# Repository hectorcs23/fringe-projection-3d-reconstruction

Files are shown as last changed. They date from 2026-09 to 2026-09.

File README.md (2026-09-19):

# 3D Reconstruction by Fringe Projection & Phase Shifting

Structured-light 3D scanner built from a consumer camera and a mini projector. Sinusoidal fringe patterns are projected onto an object, the phase of the deformed fringes is recovered with a **4-step phase-shifting** algorithm, unwrapped with **multi-frequency temporal unwrapping**, converted to height by **triangulation**, and exported as a **3D-printable STL**.

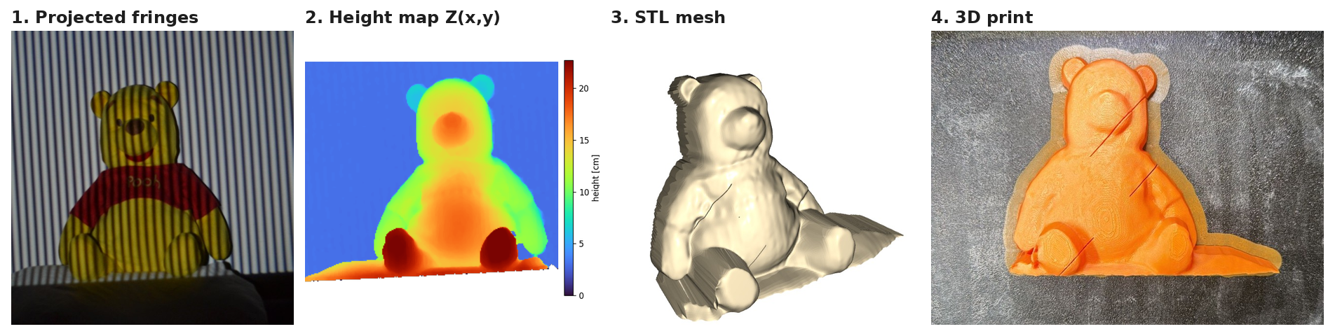
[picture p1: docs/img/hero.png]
Pipeline: fringes → height map → STL → 3D print


> Optics course project (ITESM Monterrey, 2026) — Hector Enrique Campbell Salas & José Feliciano Gutiérrez Rubio.
> Full report (Spanish): [`docs/Reporte_Final_fringe_projection_ES.pdf`](docs/Reporte_Final_fringe_projection_ES.pdf)

## Results at a glance

| Metric | Value |
|---|---|
| Valid pixels after modulation mask | **69.2 %** |
| Fringe frequencies (measured by FFT) | 2, 4, 18, 70 fringes across the field |
| Reconstructed object height | ~13 cm |
| Height error vs. 11 tape-measured landmarks | **RMSE 1.75 cm**, MAE 1.39 cm |
| Leave-one-out RMSE (honest out-of-sample) | 2.09 cm |
| Mono- vs multi-frequency difference (validation sphere) | up to ~0.4 rad (~7 mm) at the center |

The largest errors sit exactly where the physics predicts them: red regions (shirt) absorb the projected light and kill fringe modulation, and the steep sides of the object sit in projector shadows.

## How it works

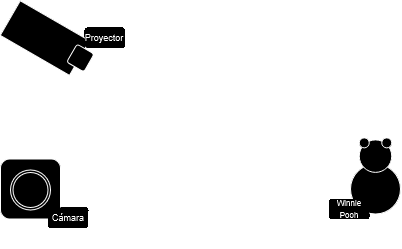
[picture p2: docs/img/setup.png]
Setup


Camera (Canon M50 Mark II) and projector sit side by side, **L = 1450 mm** from a white reference board, with a baseline **d**. For each frequency, four patterns shifted by 0, π/2, π, 3π/2 are captured on the reference board and on the object.

1. **N-step phase shifting.** Each capture follows $I_k = A + B\cos(\varphi + \delta_k)$ with $\delta_k = 2\pi k/N$, so

```math
\varphi = \mathrm{atan2}\left(-\sum_k I_k \sin\delta_k,\ \sum_k I_k \cos\delta_k\right), \qquad B = \frac{2}{N}\sqrt{C^2 + S^2}
```

2. **Modulation mask.** Keep pixels with $B > \alpha \max B$ (drops shadows, saturation, dark/red regions).
3. **Object − reference** wrapped phase difference at each frequency.
4. **Multi-frequency temporal unwrapping.** The low frequency (no 2π jumps) sets the fringe order of the next one:

```math
k_m = \mathrm{round}\left[\frac{\frac{N_m}{N_{m-1}}\Phi_{m-1} - \varphi_m}{2\pi}\right], \qquad \Phi_m = \varphi_m + 2\pi k_m
```

5. **Phase → height.** Linear triangulation with $K = Lp/(2\pi d) \approx 17.9$ mm/rad for the 70-fringe pattern:

```math
h(x,y) = K \, \Delta\varphi(x,y)
```

6. **Meshing.** Each 2×2 block of valid pixels becomes two triangles → STL (Open3D), smoothed and printed.

## Validation: sphere first

A polystyrene hemisphere was reconstructed with single-frequency spatial unwrapping and with multi-frequency temporal unwrapping. Multi-frequency recovered more detail at the center, so it was used for the complex object.

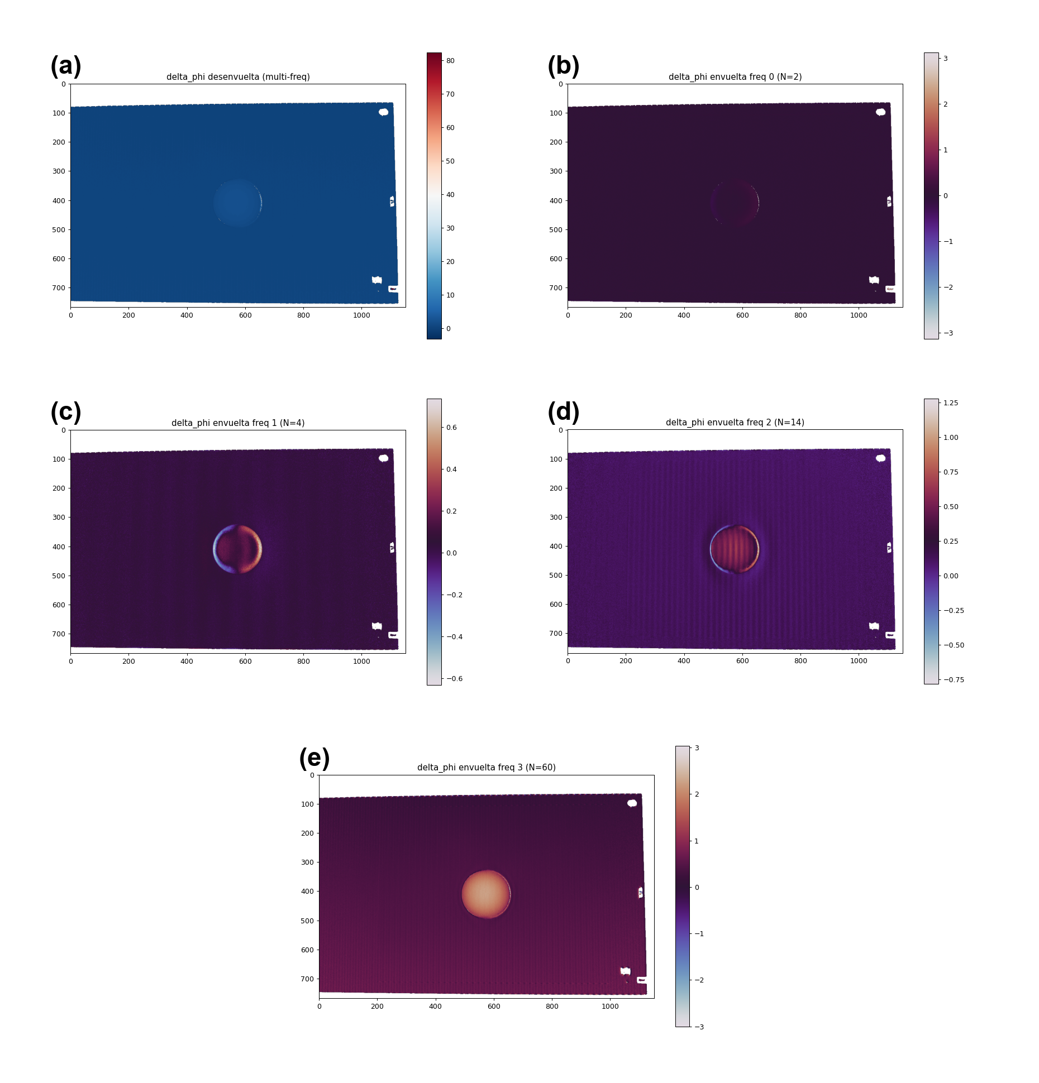
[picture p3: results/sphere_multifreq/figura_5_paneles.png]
Multi-frequency on the sphere


## Error analysis

11 landmarks (feet, hands, ears, eyes, nose, belly, shirt) were measured with a tape measure (±0.1 cm) and compared against the reconstruction (`src/error.py`), including leave-one-out validation of the phase→cm calibration.

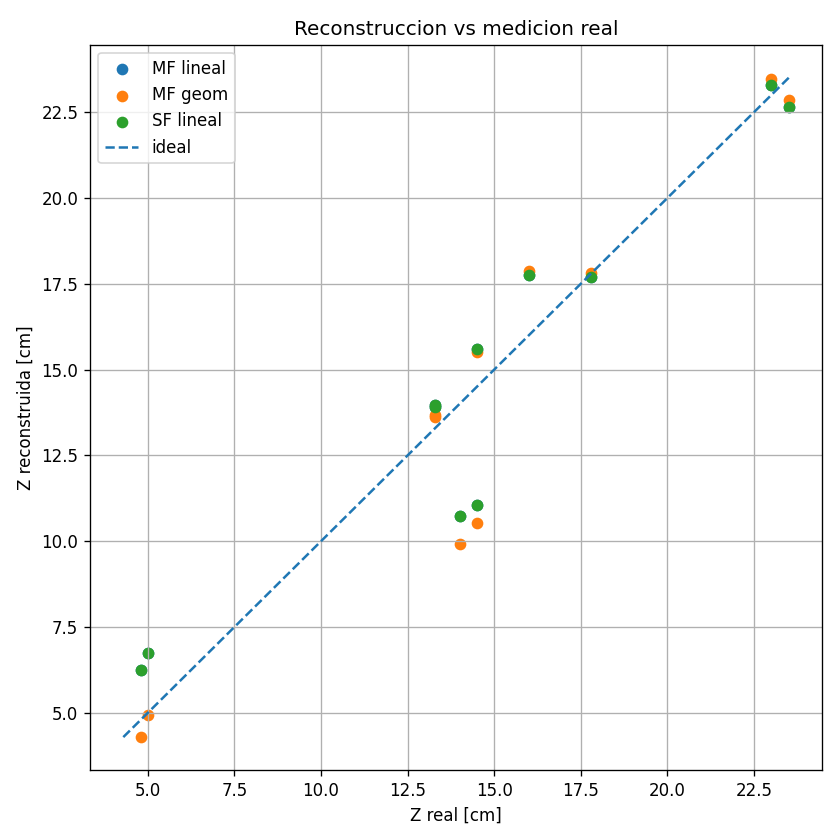
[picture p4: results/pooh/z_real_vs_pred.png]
Real vs reconstructed


## What didn't work (and what I'd do next)

I also captured the object from several angles (3 × 120° and 12 × 30°) and tried to fuse the views with ICP. Without a calibrated turntable the views don't share a known rotation axis, so the point clouds never registered cleanly, and the final model uses the frontal view only. Next steps:

- calibrated rotary stage or fiducial markers for multi-view registration,
- full triangulation equation instead of the linear approximation,
- camera/projector calibration (intrinsics + gamma) to reduce systematic phase error.

## Repository layout

```
src/
  phase_shifting.py      core library: N-step phase, mask, multi-freq unwrap, phase→height
  SuperficieSTL.py       heightmap → triangle mesh → STL (Open3D)
  process_pooh.py        main pipeline on the plush toy (front view)
  generate_pooh_stl.py   calibrated height map → printable STL
  error.py               landmark-based error analysis (MAE/RMSE, LOO, Monte Carlo)
  sphere_multifreq.py    validation: multi-frequency on the hemisphere
  sphere_singlefreq.py   validation: single-frequency on the hemisphere
  compare_methods.py     mono- vs multi-frequency comparison
  measure_freqs.py       measures real fringe counts via FFT
  demo_synthetic.py      self-contained synthetic demo (no photos needed)
data/
  pooh_front/            32 photos: 4 freq × 4 shifts, object + reference (downscaled)
  sphere/                32 photos: same protocol on the hemisphere (downscaled)
results/                 figures, STL, error tables
docs/                    report (Spanish) and README images
```

## Run it

```bash
pip install -r requirements.txt
python src/process_pooh.py        # phase maps, mask, unwrapped phase -> results/pooh/
python src/generate_pooh_stl.py   # -> results/pooh/pooh.stl
python src/error.py               # error analysis (reuses saved landmark picks)
python src/sphere_multifreq.py    # validation on the hemisphere
```

Run from the repository root. Photos in `data/` are downscaled copies of the originals (Canon M50, 4608×3072); the full-resolution captures are available on request.

## Stack

Python · NumPy · SciPy · scikit-image · Pillow · Matplotlib · Open3D · SolidWorks (mesh cleanup) · FDM 3D printing

## References

1. R. Juarez-Salazar, S. Esquivel-Hernandez, V. H. Diaz-Ramirez, "Optical Fringe Projection: A Straightforward Approach to 3D Metrology," *Metrology* 5, 47 (2025).
2. K. J. Gåsvik, *Optical Metrology*, 3rd ed., Wiley (2002).
3. E. Hecht, *Optics*, 5th ed., Pearson (2017).

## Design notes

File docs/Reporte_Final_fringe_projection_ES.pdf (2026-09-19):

Reconstrucción 3D mediante proyección de franjas y desplazamiento de fase

Hector Enrique Campbell Salas and José Feliciano Gutiérrez Rubio Instituto Tecnológico de Estudios Superiores de Monterrey (Dated: 3 de mayo de 2026)

I. OBJETIVO

Implementar un sistema de reconstrucción tridimensional basado en proyección de franjas, con el propósito de comprender cada etapa de la técnica: desde la proyección de patrones sinusoidales y la captura de imágenes, pasando por la recuperación de fase mediante desplazamiento de fase y desenvolvimiento multifrecuencia, hasta la conversión geométrica a un mapa de altura y la generación de una malla STL. El sistema se valida primero con un objeto de geometría conocida (semiesfera) y posteriormente se aplica a un objeto de geometría compleja (peluche de "Winnie pooh") para evaluar el desempeño de la técnica en condiciones más robustas.

II. DESCRIPCIÓN

Se implementa un sistema de reconstrucción tridimensional basado en metrología óptica por proyección de franjas, con el propósito de registrar con una cámara la deformación aparente de dichas franjas sobre su superficie, el arreglo óptico se muestra en la figura 1.

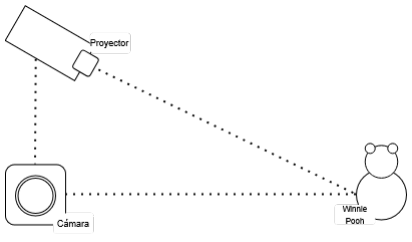
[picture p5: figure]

Figura 1. Arreglo experimental utilizado para la proyección de franjas, mostrando la posición relativa entre el proyector, la cámara y el objeto.

Se capturaron imágenes de referencia sobre una cartulina plana y posteriormente imágenes de un oso de peluche "Winnie Pooh". Se aplicó un algoritmo de desplazamiento de fase de cuatro pasos para recuperar la fase envuelta del patrón. Después, mediante un esquema multifrecuencia, se realizó el desenvolvimiento de fase para obtener una fase continua asociada al relieve de la superficie. Finalmente, la fase desenvuelta se convirtió en un mapa escalar de alturas. Con dicho mapa se generó una malla tipo STL, la cual puede utilizarse para visualización o impresión 3D.

A. Materiales y equipo

Cámara digital Canon M50 Mark II.

Proyector digital Bigview Mini Proyector HY300.

Cartulina blanca de 50 × 65 cm como plano de referencia.

Semiesfera de poliestireno como objeto de geometría conocida.

Peluche “Winnie Pooh” como objeto de geometría compleja.

Computadora con Python 3.12 para el procesamiento de imágenes.

SolidWorks y Open3D para visualización, edición y exportación del modelo 3D.

III. MARCO TEÓRICO

A. Metrología óptica

La metrología óptica es una rama de la óptica que mide propiedades físicas un objeto, tales como su forma, distancia, altura y superficie.
En dicha área, conocer la fase es importante pues está directamente relacionada con el camino óptico que recorre la luz al incidirla sobre cualquier objeto. Además esta relación permite entender por qué pequeños cambios geométricos en una superficie pueden producir cambios medibles en la fase de la luz.
Sin embargo, las cámaras registran intensidades y no la fase, por ello son necesarios crear métodos experimentales y computacionales que permitan recuperar la información física del objeto a estudiar a partir de imágenes de intensidad.
B. Proyección de Franjas

La proyección de franjas es una técnica de metrología óptica en la que se ilumina un objeto con un patrón pe-

2

riódico de franjas claras y oscuras. Al proyectarse sobre una superficie plana, el patrón observado se mantiene regular; sin embargo, cuando incide sobre una superficie con relieve, la forma del objeto modifica la rectitud y posición aparente de las franjas [1]. Esta deformación corresponde a una alteración de fase, por lo que la información geométrica de la superficie puede recuperarse mediante el análisis del patrón capturado por la cámara [1, 2].

C. Recuperación de Fase Mediante Desplazamiento de Fase

La intensidad registrada para el k-ésimo patrón está dada por:

Ik(x, y) = A(x, y) + B(x, y) cos[φ(x, y) + δk] (1)

donde A(x, y) representa la componente promedio de iluminación, B(x, y) la modulación o contraste local de las franjas, φ(x, y) la fase que se desea recuperar y δk el desfase conocido aplicado al k-ésimo patrón [2].
La ecuación (1) contiene tres incógnitas por píxel: A, B y ϕ. Por ello, una sola imagen no es suficiente para determinar la fase. Es así que se realiza un desarrollo matemático descrito en el Apéndice A y se obtienen las siguientes expresiones:
φ(x, y) = atan2(S, C), | (2)

B(x, y) = 2
N

p
C² + S², | (3)

A(x, y) = 1
N

N

X⁻¹

k=0

Ik(x, y), | (4)

donde (2) representa la fase recuperada, (3) la modulación píxel a píxel y (4) la componente de fondo.

D. Desplazamiento de Fase: Cuatro Pasos

En particular, para N = 4, los desfases aplicados al patrón proyectado son:

δk = 0,

π
2

, π,

3π
2
. | (5)

Este caso permite obtener dos componentes en cuadratura de la señal de franjas: una asociada a cos ϕ y otra asociada a sin ϕ. Sustituyendo estos desfases en el modelo de intensidad, se obtiene:

I0 = A + B cos ϕ, | (6)
I1 = A − B sin ϕ, | (7)
I2 = A − B cos ϕ, | (8)
I3 = A + B sin ϕ. | (9)

Al combinar imágenes separadas por un desfase de π, la componente promedio de iluminación se cancela, mientras que la parte modulada se conserva. A partir de estas dos componentes, la fase envuelta se obtiene mediante la ecuación (10)

ϕenv(x, y) = atan2 [I3 − I1, I0 − I2] . (10)

Este esquema es conveniente porque elimina la componente de fondo antes de calcular la fase y reduce la dependencia directa con la amplitud local de las franjas. No obstante, la fase obtenida mediante (10) permanece restringida al intervalo (−π, π], por lo que la fase obtenida corresponde a una fase envuelta.

E. Desenvolvimiento Mediante Monofrecuencia

El desenvolvimiento mediante monofrecuencia parte de una única fase envuelta φ

w(x, y) ∈ (−π, π] y busca recuperar una fase continua Φ(x, y) a partir de la comparación entre píxeles vecinos. La idea principal es que, si la superficie es continua y el ruido es bajo, la diferencia de fase entre puntos adyacentes debe ser pequeña. Cuando aparece un salto cercano a ±2π, este se interpreta como una discontinuidad artificial producida por la naturaleza periódica de la fase envuelta. En ese caso, el algoritmo corrige la fase sumando o restando múltiplos de 2π, con el fin de reconstruir una fase continua. De esta forma, el método convierte una fase limitada al intervalo (−π, π] en una fase continua que puede relacionarse con la geometría del objeto.
Sin embargo, este procedimiento depende de la continuidad espacial de la superficie. Si existen discontinuidades reales de altura, sombras, o regiones con baja modulación, el algoritmo puede confundir un salto físico con un salto artificial de fase. Por esta razón, el desenvolvimiento espacial monofrecuencia es adecuado para superficies suaves, pero puede ser insuficiente en objetos con geometría compleja donde se requiere un desenvolvimiento mediante multifrecuencia.
F. Desenvolvimiento Mediante Multifrecuencia

Para objetos con geometrías complejas se utiliza un algoritmo mediante multifrecuencia. El algoritmo consiste en la proyección de franjas a diferentes frecuencias, además el algoritmo es recursivo ya que comienza

3

desde frecuencias bajas hasta las frecuencias más altas. Las frecuencias bajas presentan menos saltos de fase, sin embargo, sirven como guía para determinar el orden correcto de franja. Por otro lado, las frecuencias altas proporcionan mayor sensibilidad a los cambios de altura y permiten recuperar más detalles de la superficie. Sea Φm(x, y) la fase desenvuelta a la frecuencia Nm. Para cada frecuencia Nm, se obtiene primero una fase envuelta φ

w
m(x, y). A partir de la fase desenvuelta de la frecuencia anterior, Φm−1(x, y), se estima la fase esperada en la nueva frecuencia. La estimación se expresa en la ecuación (11)

Φ

esp

m (x, y) = Nm

Nm−1

Φm−1(x, y). | (11)

Donde Nm−1 es la frecuencia anterior y Φm−1(x, y) es la fase anterior.
Posteriormente, se determina el orden de franja entero km que más cerca está de la fase esperada:
km(x, y) = round
Φ

esp
m (x, y) − ϕ

w
m(x, y)
2π
. (12)

Finalmente, se reconstruye la fase desenvuelta a la nueva frecuencia:

Φm(x, y) = ϕ

w
m(x, y) + 2πkm(x, y). | (13)
G. De fase a altura: Triangulación

La fase desenvuelta no representa directamente la altura del objeto, solo indica cómo se desplazó el patrón de franjas observado por la cámara respecto a una referencia plana. Para convertir esa diferencia de fase en una magnitud geométrica, es necesario utilizar la geometría del sistema cámara-proyector.
La diferencia de fase se relaciona con el desplazamiento lateral del patrón. Si p es es el periodo de las franjas sobre el plano de referencia, entonces el desplazamiento asociado a la diferencia de fase se expresa según la ecuación (14)

AB =

p ∆ϕ(x, y)
2π
. | (14)

Por triángulos semejantes, este desplazamiento se relaciona con la altura h(x, y) del objeto. Para el modelo geométrico utilizado, la altura puede expresarse según la ecuación (15).

h(x, y) = L ∆ϕ(x, y)
∆ϕ(x, y) −

2πd
p
, | (15)

donde L es la distancia del proyector al plano de referencia, d es la línea de base entre proyector y cámara, y p el periodo de franjas proyectadas sobre el plano de referencia.

IV. METODOLOGÍA

A. Arreglo experimental y selección de objetos

Se seleccionaron dos objetos para evaluar el método de reconstrucción. El primer objeto fue una media esfera de poliestireno, utilizada como prueba inicial debido a su geometría simple y superficie relativamente uniforme. El segundo objeto fue un oso de peluche “Winnie Pooh”, elegido por presentar una geometría más compleja, textura superficial y variaciones de color.
El arreglo experimental estuvo compuesto por un proyector, una cámara digital, una cartulina utilizada como plano de referencia y el objeto a reconstruir. El proyector y la cámara se colocaron aproximadamente en el mismo plano horizontal, separados por una línea de base d. La distancia entre el proyector y el plano de referencia fue L. Durante la captura se mantuvo fija la posición relativa entre cámara, proyector y plano de referencia, con el fin de evitar cambios artificiales en la fase medida.

Tabla I. Parámetros geométricos del arreglo experimental.

Parámetro | Símbolo | Valor
Distancia proyector–plano | L | 1450 mm
Línea de base proyector–cámara | d | 200 mm
Cartulina iluminada (ancho) | – | 650 mm
Cartulina iluminada (alto) | – | 500 mm
Resolución cámara (orig.) | – | 4608 × 3072
B. Proyección de franjas y captura de imágenes

Para la captura experimental se proyectaron patrones sinusoidales de franjas sobre una cartulina utilizada como plano de referencia y, posteriormente, sobre el objeto a reconstruir.
Debido a que la cámara y el proyector se encontraban separados horizontalmente, las franjas proyectadas fueron verticales. Esta orientación permite que los cambios de altura del objeto produzcan un desplazamiento aparente de las franjas en la dirección donde varía la fase.
Para cada frecuencia se proyectaron cuatro patrones con desplazamientos de fase de 0, π/2, π y 3π/2. Este procedimiento se realizó primero sobre el plano de referencia y después sobre el objeto seleccionado, manteniendo fija la posición relativa entre cámara, proyector y plano de referencia.

4

C. Procesamiento general

El procesamiento de las imágenes siguió el flujo mostrado en la Fig. 2. El algoritmo computacional recibe

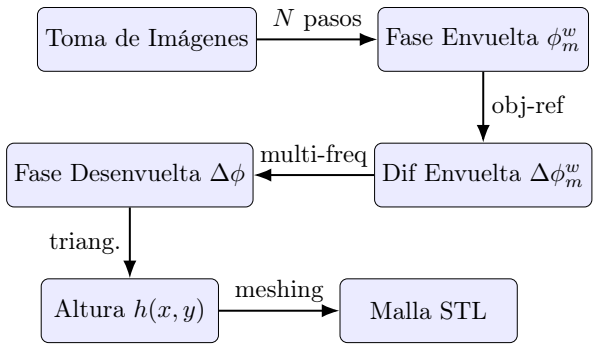
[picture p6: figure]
Toma de Imágenes; Fase Envuelta ϕ; Dif Envuelta ∆ϕ; w Fase Desenvuelta ∆ϕ; Altura h(x, y); Malla STL; N pasos; obj-ref; multi-freq; triang.; meshing

Figura 2. Procesamiento computacional implementado para la reconstrucción 3D de los objetos seleccionados.

como entrada las imágenes JPG correspondientes a cada frecuencia y desfase. Después, mediante el algoritmo de N pasos, se obtuvo la fase envuelta ϕ

w
m para cada
frecuencia m.
Posteriormente se calculó la diferencia de fase envuelta entre el objeto y la referencia, ∆ϕ

w
m. Esta resta permitió reducir la contribución del fondo y conservar principalmente la deformación del patrón producida por el relieve del objeto. Después se aplicó el desenvolvimiento multifrecuencia para obtener una fase continua ∆ϕ. Finalmente, esta fase se convirtió en un mapa de alturas h(x, y), a partir del cual se generó una malla STL.
D. Recuperación de fase por cuatro pasos

Una vez capturadas las imágenes, se aplicó el algoritmo de desplazamiento de fase de cuatro pasos para cada frecuencia proyectada. Este proceso se realizó por separado para las imágenes de referencia y para las imágenes del objeto.
A partir de estas capturas, el algoritmo permitió obtener tres mapas principales: la fase envuelta, la modulación de las franjas y la componente promedio de iluminación. La fase envuelta contiene la información asociada a la deformación del patrón; la modulación indica la calidad local de las franjas; y la componente promedio permite identificar regiones demasiado oscuras o saturadas.
Computacionalmente, esta etapa se implementó mediante una función que recibe una lista de imágenes desplazadas en fase y devuelve la fase envuelta, la modulación y la componente promedio. En el pipeline, esta etapa corresponde al paso de imágenes JPG a fase envuelta ϕ

w
m.
E. Desenvolvimiento multifrecuencia

Para resolver la ambigüedad de fase se utilizó un desenvolvimiento temporal multifrecuencia. Primero, para cada frecuencia proyectada, se obtuvo una fase envuelta tanto del plano de referencia como del objeto. Posteriormente, se calculó la diferencia envuelta objeto– referencia para cada frecuencia, de modo que la fase común del patrón proyectado se cancelara antes del desenvolvimiento.
Las diferencias de fase se ordenaron de menor a mayor frecuencia. La frecuencia más baja se utilizó como punto de partida debido a que contiene menos discontinuidades de 2π. Después, el algoritmo utilizó esta fase como guía para desenvolver progresivamente las fases de frecuencias mayores. Este proceso permitió combinar la estabilidad de las frecuencias bajas con la mayor sensibilidad de las frecuencias altas.
Una vez realizado lo anterior, se obtuvo una fase desenvuelta continua que fue utilizada como entrada para la conversión de fase a altura.
F. De fase desenvuelta a modelo 3D

Una vez obtenida la fase desenvuelta ∆φ(x, y) mediante el desenvolvimiento multifrecuencia, se convirtió la información de fase en un mapa de altura. Primero se aplicó una máscara basada en la modulación B(x, y), con el fin de conservar únicamente las zonas donde las franjas se distinguían con suficiente claridad. De esta manera se descartaron regiones con sombras, saturación, bajo contraste o absorción de luz por parte del objeto.
Posteriormente, sobre los píxeles válidos se aplicó la relación fase–altura descrita en la sección III.G. En la implementación final se utilizó una calibración lineal de la forma
h(x, y) = K∆φ(x, y), | (16)

donde K = 17,9 mm/rad corresponde a la constante utilizada para la frecuencia más alta. Con esta conversión se obtuvo un mapa de altura en milímetros para cada vista capturada.
Después, cada píxel válido del mapa de altura se interpretó como un punto tridimensional (X, Y, Z), donde X e Y representan la posición lateral en la imagen y Z = h(x, y) la altura reconstruida. De esta manera se generó una nube de puntos asociada a cada vista del objeto.
Para intentar reconstruir el objeto completo, se capturaron distintas vistas del peluche y se intentó alinearlas mediante ICP (Iterative Closest Point). Sin embargo, al no contar con una base rotatoria calibrada, las

5

vistas no compartieron un eje de rotación común. Esto produjo desplazamientos entre las nubes de puntos y evitó una alineación estable. Por esta razón, el modelo final se construyó únicamente a partir de la vista frontal.
Finalmente, la nube de puntos frontal se convirtió en una malla triangular conectando píxeles vecinos válidos. La malla resultante se exportó en formato STL, lo que permitió visualizarla en Open3D, editarla en Solid-Works e imprimirla en 3D. Los detalles computaciones se presentan en el Apéndice B.
V. RESULTADOS

Esta sección presenta los resultados obtenidos en dos etapas. Primero se utilizó una semiesfera como objeto de prueba para comparar el desenvolvimiento monofrecuencia y multifrecuencia, con el fin de seleccionar la metodología más adecuada para un objeto de mayor complejidad. Posteriormente se aplicó el algoritmo seleccionado a la reconstrucción de un peluche tipo ‘Winnie Pooh’.
Para el caso de la semiesfera, se realizaron tanto el desenvolvimiento por una frecuencia así como el multifrecuencia y se observaron los resultados con el fin de saber la metodología a seguir en un objeto más robusto. Se usaron las mismas foto y se muestra la diferencia entre los procesos de desenvolvimiento. Para el caso

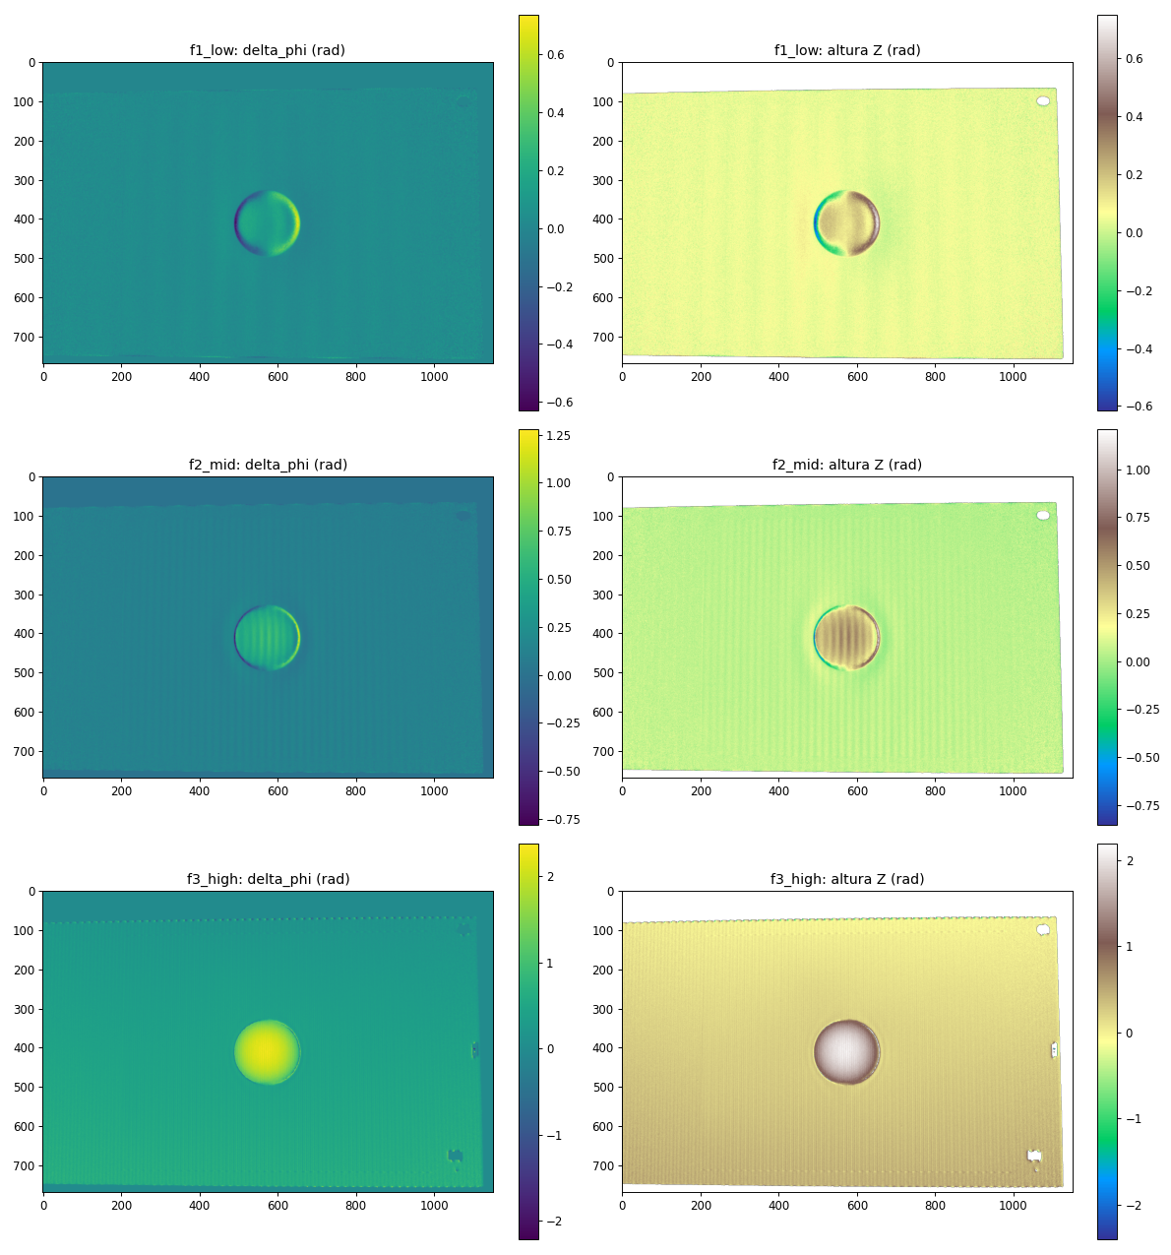
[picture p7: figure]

Figura 3. Fases recuperadas para la semiesfera utilizando cada una de las frecuencias proyectadas

Y después mediante el algoritmo de multifrecuencias:

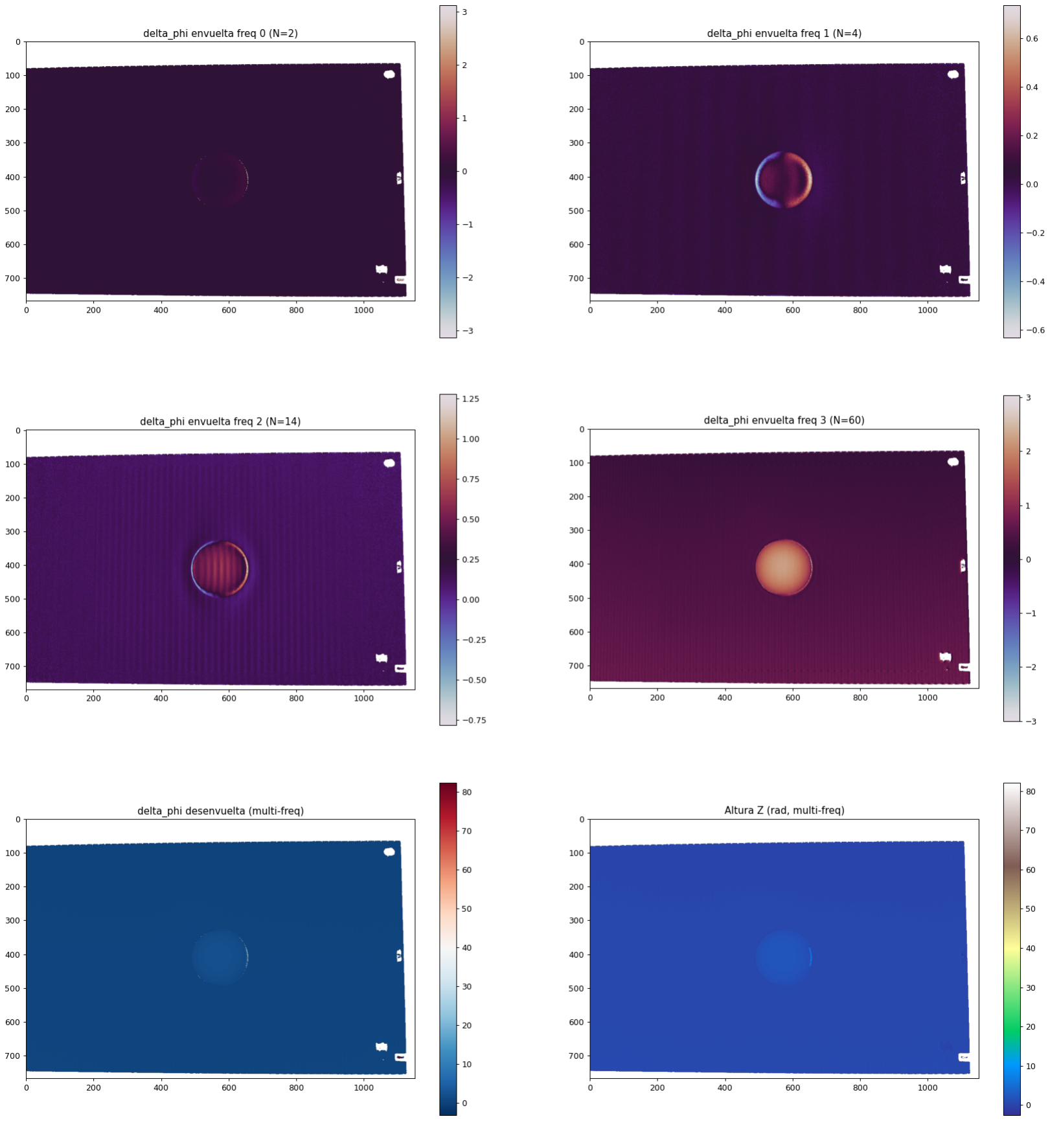
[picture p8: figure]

Figura 4. Resultado del desenvolvimiento multifrecuencia aplicado a la semiesfera.

La diferencia entre el desenvolvimiento de la frecuencia más alta y el desenvolvimiento de multifrecuencia llegó a un máximo de 0.4 rad, alrededor de 7 milimetros en el centro. Se observa que el resultado obtenido por multifrecuencia (Fig. 4) presenta mayor nivel de detalle en el centro de la esfera en comparación con el desenvolvimiento monofrecuencia (Fig. 3).

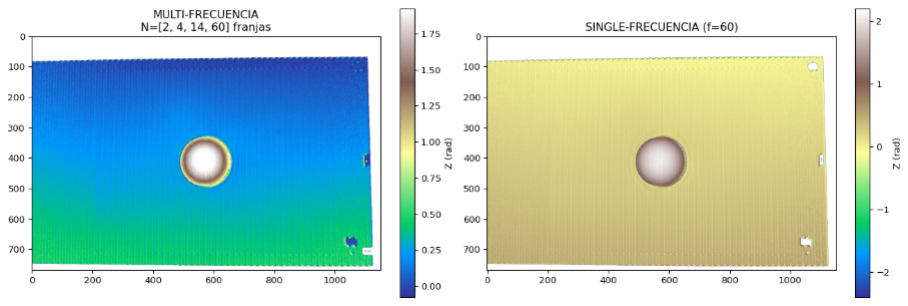
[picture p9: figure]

Figura 5. Comparación entre la fase obtenida mediante desenvolvimiento monofrecuencia y multifrecuencia.

6

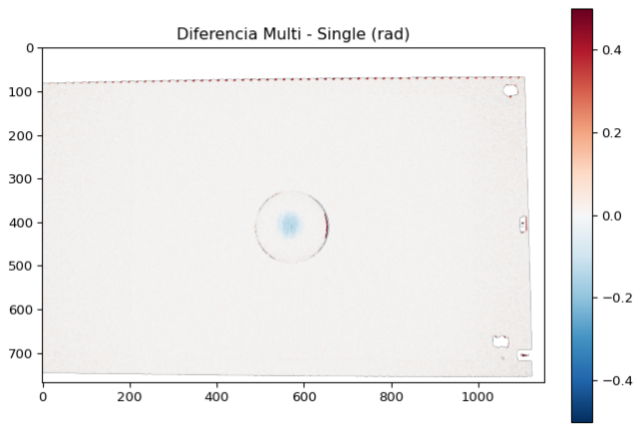
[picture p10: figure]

Figura 6. Diferencia de fase entre el resultado monofrecuencia y el resultado multifrecuencia.

Debido a que el arreglo fue desarrollado bajo condiciones que podían permitir errores, se concluyó que la mejor opción para avanzar era el desenvolvimiento multifrecuencia, por lo que se desarrolló el procedimiento estipulado en la sección pasada para obtener el modelo 3D de las siguientes imágenes.

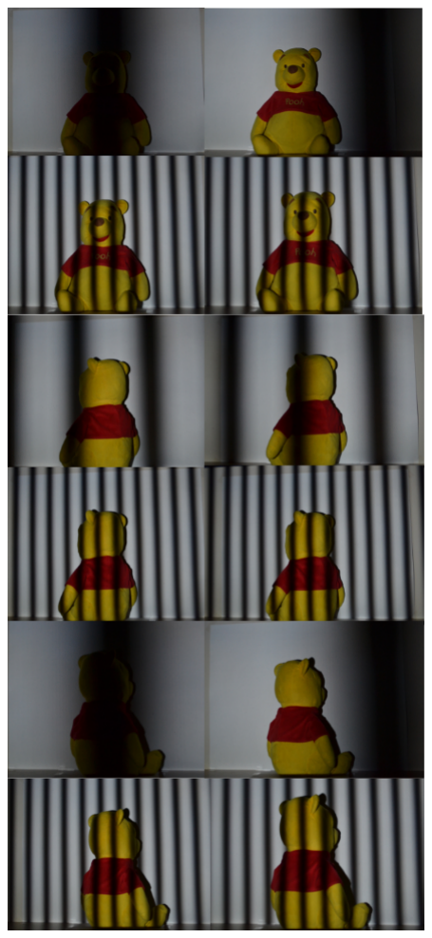
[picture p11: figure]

Figura 7. Imágenes capturadas del peluche desde distintas vistas, con una separación angular aproximada de 120◦

El 69.2 % de los píxeles superaron la máscara. La pérdida respecto al caso de la esfera se debe a:

Zonas rojas, como la camisa, que absorben la luz proyectada y producen una modulación cercana a cero.

Sombras generadas por el proyector en las zonas laterales del peluche.

Textura del peluche, la cual introduce ruido.

La modulación en las tomas frontales quedó de la siguiente forma:

Figura 8. Mapa de modulación de la toma frontal, utilizado para identificar regiones con bajo contraste o baja confiabilidad de fase.

Las fases envueltas quedaron de la siguiente forma:

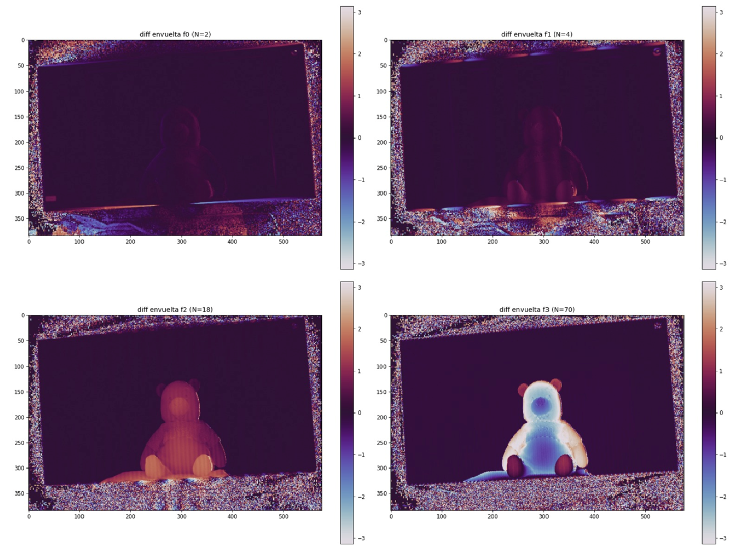
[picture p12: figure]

Figura 9. Fases envueltas recuperadas para la toma frontal del peluche a distintas frecuencias.

Se identifican claramente la cabeza, orejas, cuerpo y extremidades. La altura recuperada del peluche es de alrededor de 130 mm (calibración lineal con K = 17.9 mm/rad correspondiente a N = 70 franjas a la frecuencia más alta).

7

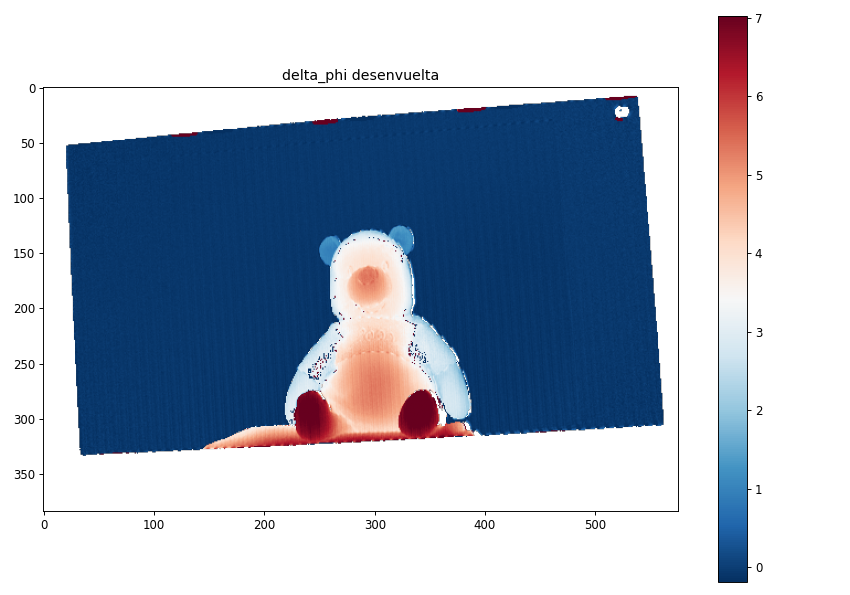
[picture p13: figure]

Figura 10. Fase desenvuelta de la vista frontal después de aplicar el algoritmo multifrecuencia.

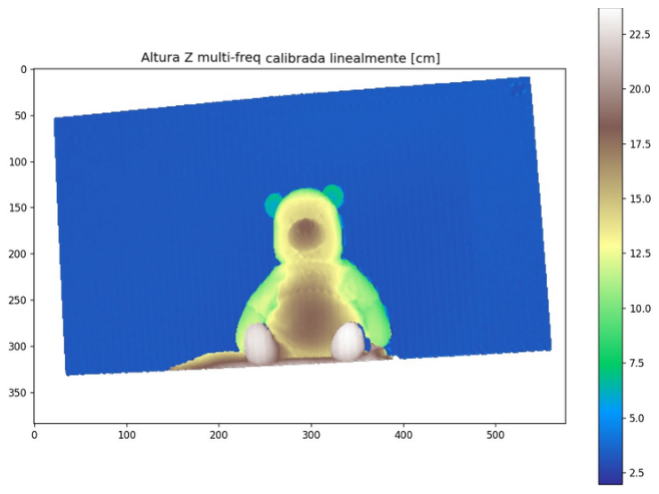
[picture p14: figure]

Figura 11. Altura extraída de la fase desenvuelta

Después se siguió el mismo procedimiento con las otras vistas de modo que se pudo capturar la altura en Z de las vistas.

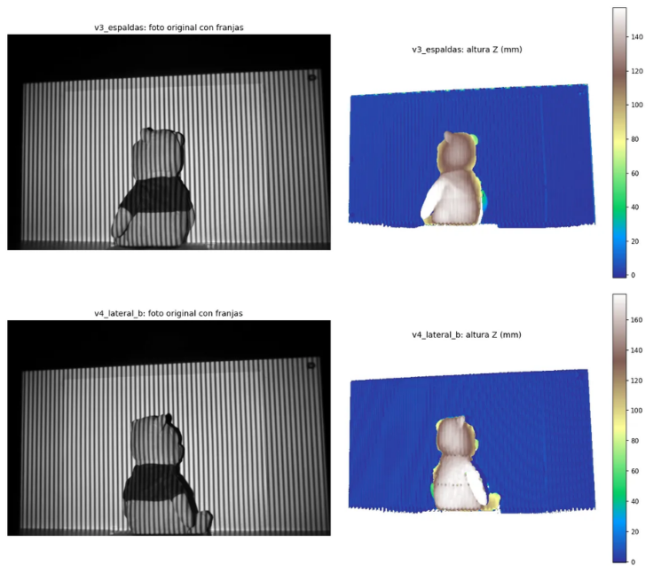
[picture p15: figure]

Figura 12. Vistas laterales del objeto

Como intento inicial de combinar las vistas, se calculó la silueta binaria del peluche en cada captura aplicando un umbral sobre la modulación B(x,y), y se buscó intersectar los perfiles proyectados al sistema común de coordenadas para acotar el volumen del objeto (Fig. 13). Sin embargo, esta estrategia mostró las mismas limitaciones de alineación descritas más adelante.

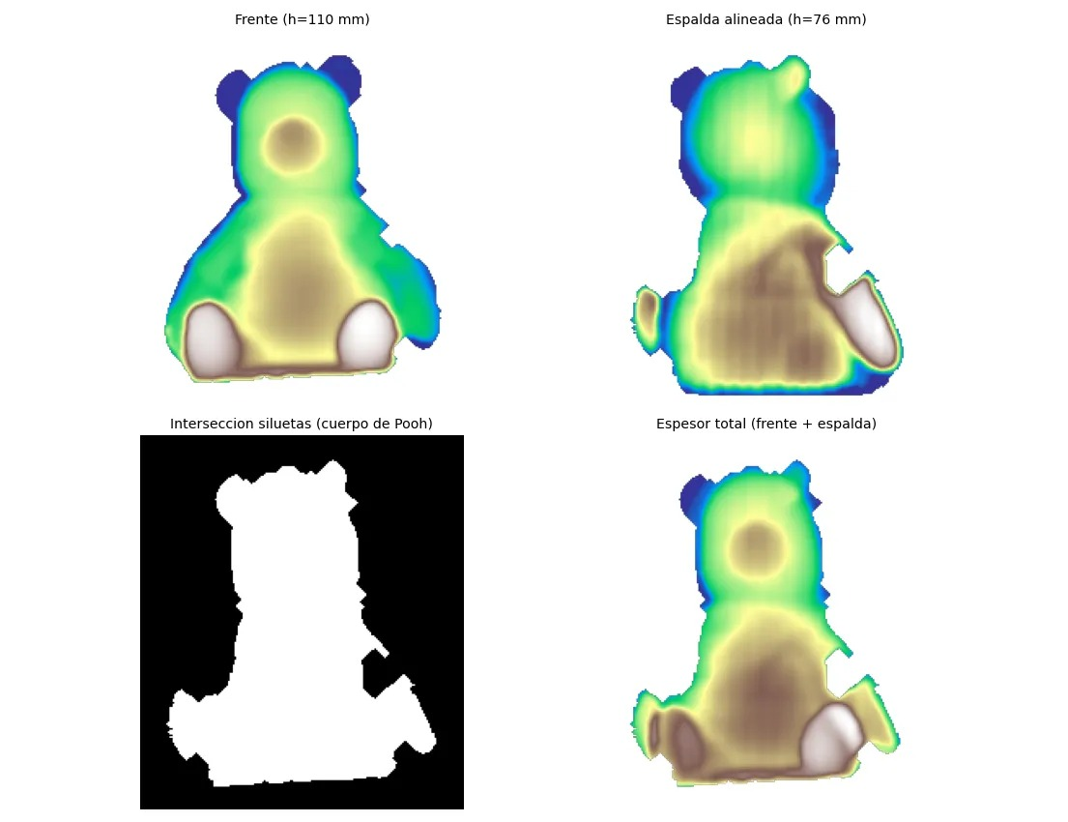
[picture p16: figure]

Figura 13. Intersección de siluetas

A pesar de tener la altura correcta, el objeto no se pudo reconstruir debido a la alineación incorrecta entre vistas, causada por un centro de rotación incorrecto.

8

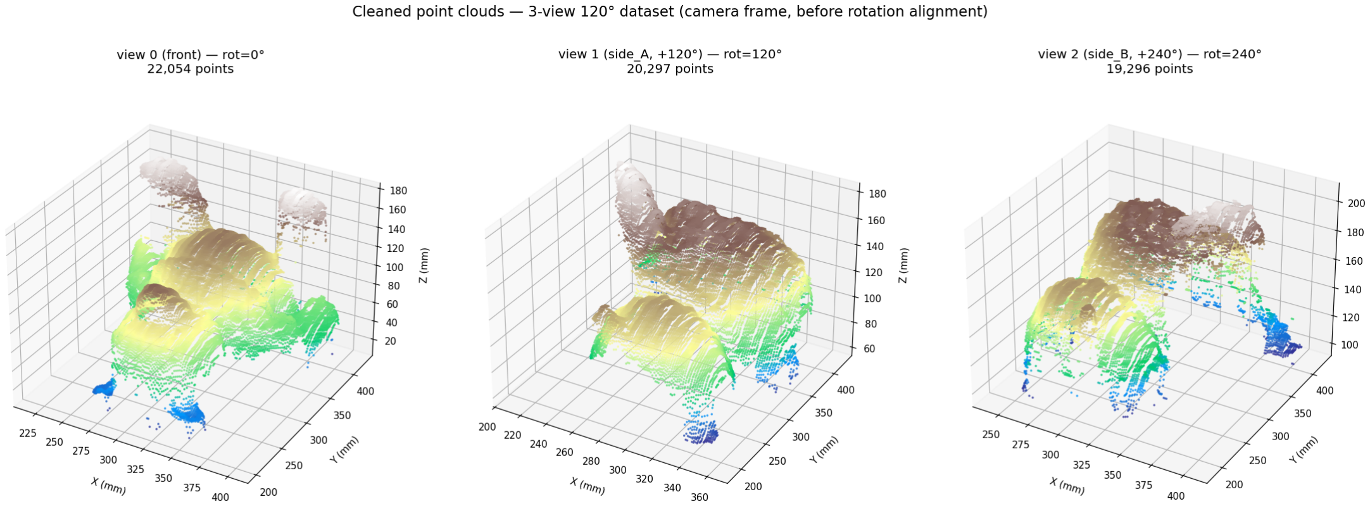
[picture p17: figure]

Figura 14. Reconstrucción de "Winnie Pooh"@

Al no haber usado una base rotatoria, era de esperar esta dificultad. En una reconstrucción adecuada, las nubes de puntos de las distintas vistas deberían superponerse al ser rotadas hacia el sistema de referencia de la vista inicial.

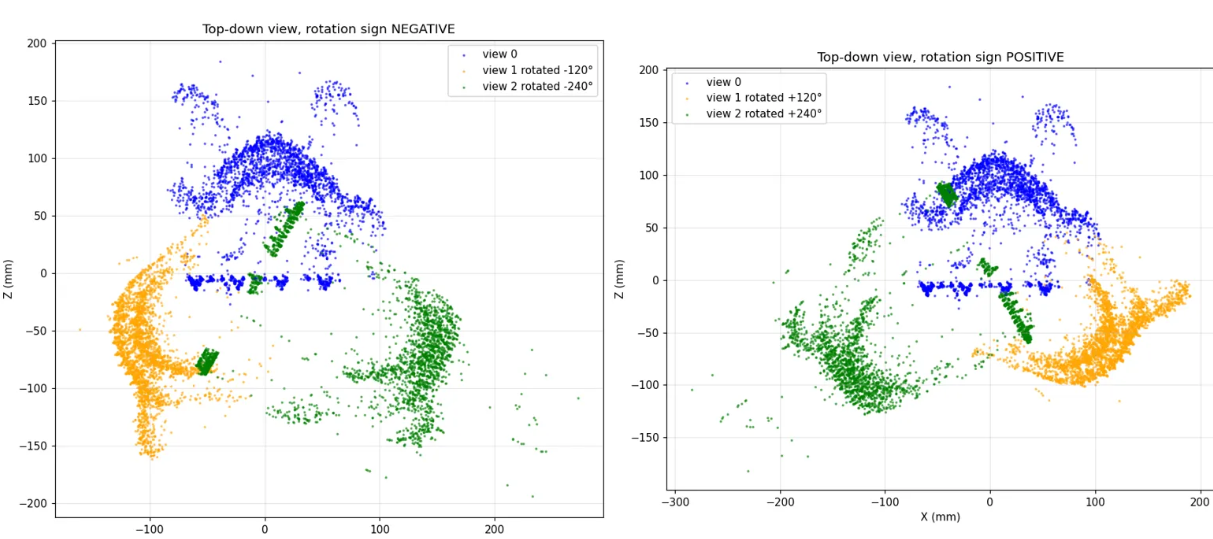
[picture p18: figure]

Figura 15. Alineación de nubes de puntos obtenidas desde distintas vistas del peluche. Se observa que las vistas no coinciden espacialmente debido a un centro de rotación no calibrado

Sin embargo, tanto con rotación positiva como negativa, las nubes permanecen separadas, por lo que el signo de la rotación no es el factor dominante. Esto indica que las vistas fueron rotadas alrededor de un eje incorrecto o que el objeto se desplazó ligeramente durante la captura.

Como consecuencia, las nubes de puntos no quedan en el mismo sistema de coordenadas, generando una reconstrucción desplazada, gruesa o con huecos. Además, el uso de solo tres vistas, el bajo solapamiento y el ruido de fase contribuyen a empeorar el resultado.

Por los problemas que hubo, el proyecto continuó con la vista frontal únicamente pero se consideró importante mencionar estos resultados y la limitación.

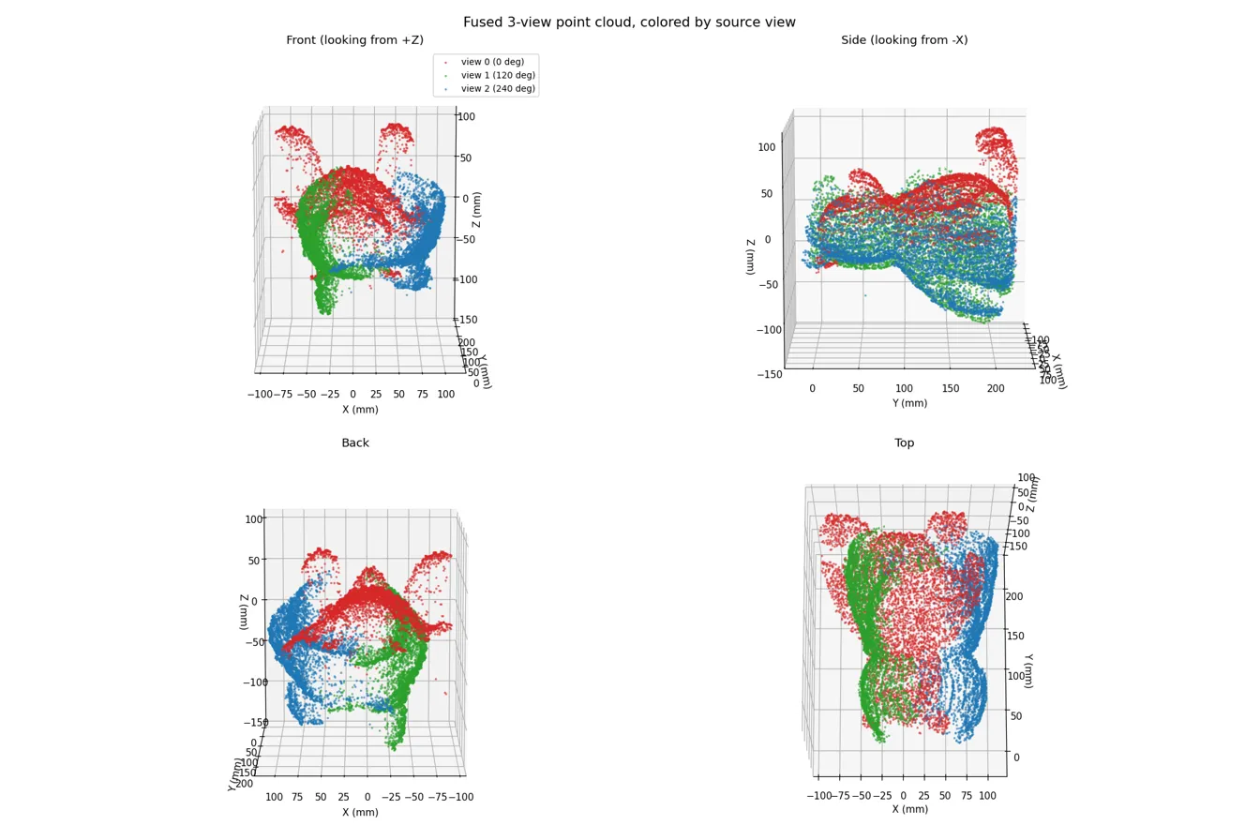
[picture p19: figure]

Figura 16. Reconstrucción de "Winnie Pooh"desde varias vistas

El resultado final aplicado al STL de la vista frontal se ve en la siguiente imagen:

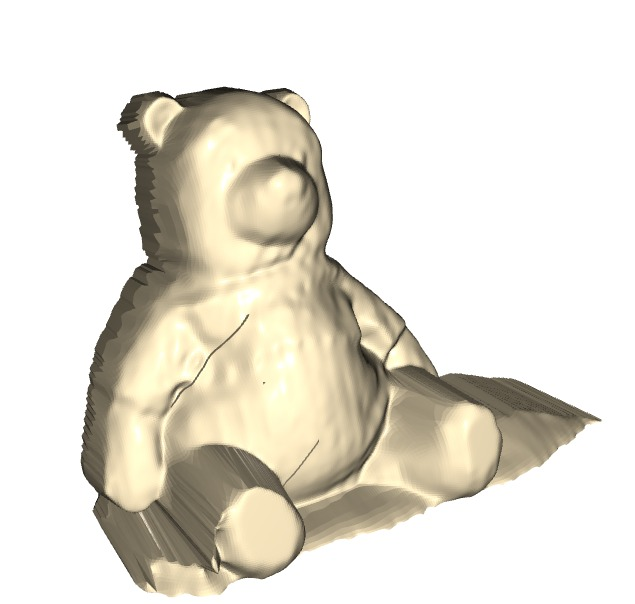
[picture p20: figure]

Figura 17. Modelo STL de "Winnie Poohüsando librería de Open3D de Python

9

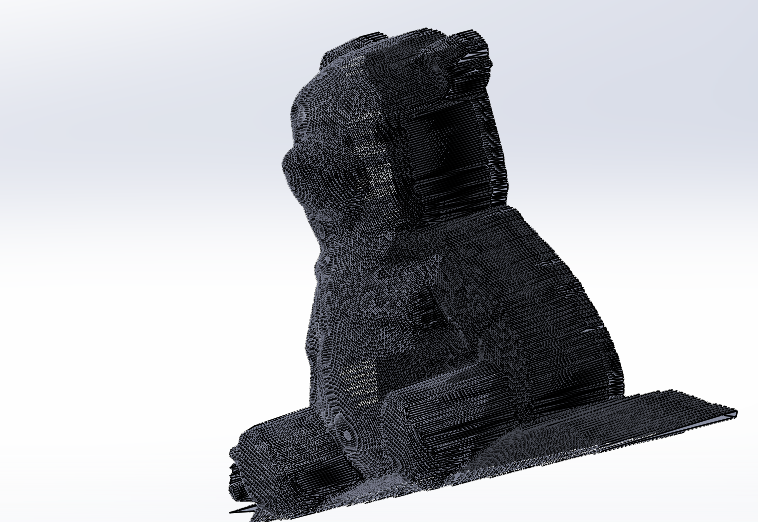
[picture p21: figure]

Figura 18. Modelo STL de "Winnie Pooh.en SolidWorks

La impresión final tuvo un buen nivel de detalle como se ve a continuación.

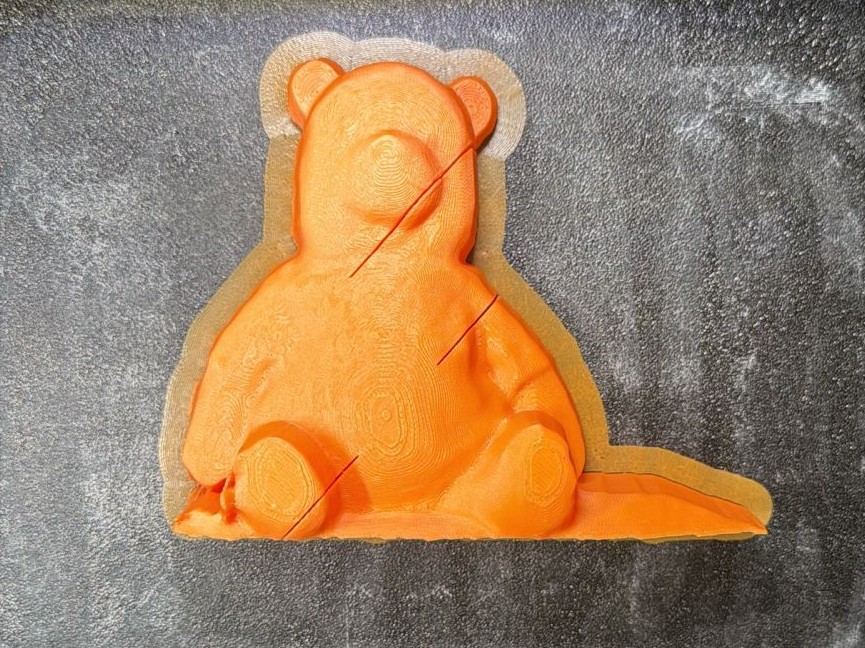
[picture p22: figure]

Figura 19. Resultado físico de la Impresión de "Winnie Pooh"@

1. Análisis de error

Para cuantificar la precisión de la reconstrucción se midieron manualmente, con flexómetro, las distancias verticales (Z) de once puntos anatómicos del peluche y se compararon contra los valores recuperados por el sistema. Los resultados se resumen en la tabla II.

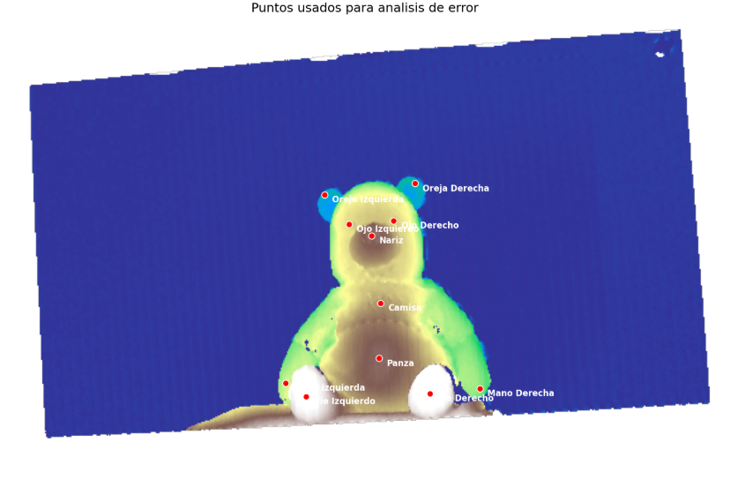
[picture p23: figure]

Figura 20. Puntos de control seleccionados sobre el peluche para comparar la altura medida con la altura reconstruida.

Tabla II. Comparación entre alturas medidas y reconstruidas.
Punto | Medición (cm) Error % |error| (cm)
Pie derecho | 23,0 ± 0,1 | 1 % | 0.27
Pie izquierdo | 23,5 ± 0,1 | -3 % | 0.81
Mano derecha | 14,0 ± 0,1 | -26 % | 3.65
Mano izquierda | 14,5 ± 0,1 | -21 % | 2.98
Oreja derecha | 5,0 ± 0,1 | 35 % | 1.73
Oreja izquierda | 4,8 ± 0,1 | 34 % | 1.62
Ojo derecho | 13,3 ± 0,1 | 4 % | 0.59
Ojo izquierdo | 13,3 ± 0,1 | 2 % | 0.25
Nariz | 17,8 ± 0,1 | 0 % | 0.08
Panza | 16,0 ± 0,1 | 11 % | 1.75
Camisa | 14,5 ± 0,1 | 8 % | 1.16

A partir de estos valores se obtuvieron los indicadores globales

MAE = 1,354 cm, | (17)
RMSE = 1,742 cm, | (18)

los cuales describen el error promedio absoluto y el error cuadrático medio sobre los once puntos. La gráfica de Zreal vs. Zreconstruida muestra que la mayoría de los puntos se distribuyen cerca de la diagonal y = x, lo que confirma una correspondencia lineal entre las mediciones reales y las recuperadas.

10

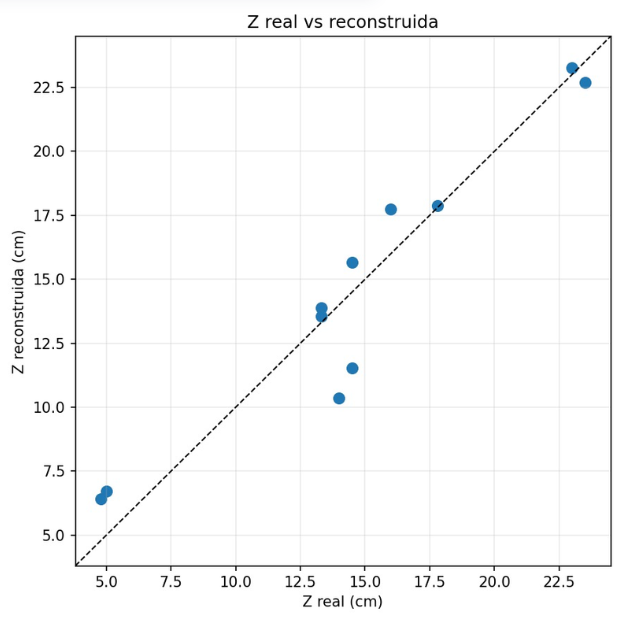
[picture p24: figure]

Figura 21. Comparación de altura real y encontrada en el algoritmo

Cabe mencionar que las mediciones de referencia fueron tomadas manualmente con un flexómetro de resolución ±0,1 cm, por lo que cada valor de la columna Medición lleva implícita esa incertidumbre. Dado que el RMSE obtenido (∼ 1,7 cm) es más de un orden de magnitud superior a la incertidumbre del instrumento, esta contribución no domina el error reportado; sin embargo, explica parte de la dispersión observada en los puntos de bajo error como la nariz y los ojos, donde el error absoluto es comparable al límite de medición manual.
Los errores no se distribuyen de manera uniforme sobre el objeto, sino que se concentran en zonas específicas, lo cual permite asociarlos a las fuentes de error características de la técnica:

Puntos de bajo error (< 1 cm): Pies, ojos y nariz. Corresponden a regiones bien iluminadas, con buena modulación del patrón de franjas y orientadas casi frontalmente respecto a la cámara, donde la fase recuperada es más confiable.

Puntos de error medio (1–2 cm): Panza, camisa y orejas. La camisa y la panza, al estar en zonas rojas, absorben parte de la luz proyectada y reducen la modulación local B(x, y), lo que aumenta directamente la incertidumbre de fase. En el caso de las orejas, aunque el error absoluto es moderado (∼ 1,7 cm), el error porcentual asciende al ∼ 34 % debido a que la altura de referencia es muy pequeña (∼ 5 cm); pequeñas desviaciones de fase se amplifican porcentualmente en regiones de baja altura.

Puntos de alto error (> 2,5 cm): Ambas manos, con errores absolutos de 2,98 y 3,65 cm. Estas regiones se encuentran en los laterales del peluche, donde el proyector genera sombras y la superficie presenta una inclinación pronunciada respecto al plano de referencia. La combinación de baja modulación, sombreado y geometría desfavorable produce un subestimación sistemática de la altura, reflejada en errores porcentuales negativos del orden del −25 %.

Los resultados anteriores son consistentes con las tres fuentes de error identificadas previamente. El ruido de fase asociado a la modulación local explica la pérdida de calidad en zonas rojas y sombreadas (manos, camisa, panza); la inconsistencia entre el desenvolvimiento monofrecuencia y multifrecuencia, estimada en ∼ 0,4 rad (∼ 0,7 cm con K = 17,9 mm/rad), contribuye al error de fondo observado en prácticamente todos los puntos; y el uso de la calibración lineal K = 17,9 mm/rad introduce una desviación sistemática que se vuelve más relevante en las regiones más altas del objeto. El RMSE de 1,742 cm sobre una altura útil de ∼ 13 cm representa un error relativo global del orden del 13 %, valor razonable considerando que el arreglo no fue calibrado geométricamente y que la superficie del peluche presenta textura, color no uniforme y sombreado lateral importante.

VI. CONCLUSIONES

En conclusión, se desarrolló una metodología para la reconstrucción 3D de objetos mediante proyección de franjas y desplazamiento de fase. También se identificaron las principales limitaciones del arreglo experimental y se analizó su efecto en los resultados obtenidos.
Se cubrieron todas las etapas características del proyecto, la proyección y captura de patrones sinusoidales con desplazamiento de fase, la recuperación de la fase envuelta mediante el algoritmo de cuatro pasos, el desenvolvimiento temporal multifrecuencia, la conversión geométrica a un mapa de altura y la generación de la malla STL final. La validación inicial con la semiesfera permitió comparar el desenvolvimiento de una frecuencia y multifrecuencia, evidenciando que este último ofrece mayor robustez y detalle, y justificando su uso en la reconstrucción del objeto principal.
En el caso del peluche, se logró recuperar correctamente la geometría general de la vista frontal, con un error cuadrático medio de 1,742 cm sobre once puntos de control, equivalente a un error relativo del orden del 13 % respecto a la altura útil del objeto. Este resultado es razonable considerando que el arreglo no fue calibra-

11

do geométricamente y que la superficie del peluche presenta condiciones desfavorables para la técnica: zonas de color rojo que absorben la luz proyectada, sombras laterales y textura no uniforme. El análisis por puntos confirmó que los mayores errores se concentran precisamente en las zonas con baja modulación o geometría inclinada, lo cual es consistente con las fuentes de error teóricas de la técnica.
La principal limitación encontrada fue la dificultad de fusionar correctamente las tres vistas capturadas, debido a la falta de una base rotatoria calibrada que garantizara un centro de rotación bien definido. El algoritmo ICP no logró converger a una alineación coherente y, en consecuencia, el modelo final se construyó únicamente con la vista frontal. Como trabajo futuro se identifican tres mejoras principales: incorporar una plataforma de rotación calibrada o marcadores fiduciales para facilitar el registro entre vistas, implementar la conversión de fase a altura usando la ecuación de triangulación completa en lugar de la aproximación lineal, y utilizar un objeto con superficie más uniforme en color y textura para reducir las pérdidas por modulación.
[1] R. Juarez-Salazar, S. Esquivel-Hernandez, and V. H. Diaz-Ramirez, “Optical Fringe Projection: A Straightforward Approach to 3D Metrology,” Metrology 5, 47 (2025).
[2] K. J. Gåsvik, Optical Metrology, 3rd ed. (John Wiley & Sons, Chichester, 2002), Chap. 11.
[3] E. Hecht, Optics, 5th ed. (Pearson, Boston, 2017), Sec. 12.3, p. 594.

Apéndice A: Solución al algoritmo de N pasos

El método de desplazamiento de fase parte del modelo de intensidad

Ik(x, y) = A(x, y) + B(x, y) cos [φ(x, y) + δk] , (A1)

donde k = 0, 1, . . . , N−1 indica el número de captura, y los desfases se eligen de forma equiespaciada como

δk =

2πk
N
. | (A2)

Para simplificar la notación, se omite la dependencia espacial (x, y). Así, para un píxel fijo se tiene

Ik = A + B cos(φ + δk). | (A3)

El objetivo es recuperar la fase φ a partir de las N intensidades registradas. Para ello, se proyecta la señal sobre las componentes cos δk y sin δk. Primero, multiplicando la ecuación (A3) por cos δk y sumando sobre todas las capturas:

N

X⁻¹

k=0

Ik cos δk =

N

X⁻¹

k=0

[A cos δk + B cos(φ + δk) cos δk]

(A4)

= 0 +

B
2

N

X⁻¹

k=0

[cos(φ + 2δk) + cos φ] (A5)

=

N
2
B cos φ. | (A6)

En este desarrollo se asumen propiedades de ortogonalidad de los desfases equiespaciados:

N

X⁻¹

k=0

cos δk = 0,

N

X⁻¹

k=0

cos(φ + 2δk) = 0. (A7)

12

Por otra parte, multiplicando por sin δk y sumando sobre todas las capturas, se obtiene

N

X⁻¹

k=0

Ik sin δk =

N

X⁻¹

k=0

[A sin δk + B cos(φ + δk) sin δk]

(A8)

= −

N
2
B sin φ. | (A9)

Se definen las cantidades C y S de la siguiente manera:

C ≡

N

X⁻¹

k=0

Ik cos δk, | (A10)

S ≡ −

N

X⁻¹

k=0

Ik sin δk. | (A11)

Por lo tanto,

C =

N
2
B cos φ, | (A12)

S =

N
2
B sin φ. | (A13)

Finalmente, la fase se recupera mediante

φ = atan2(S, C), | (A14)

y la modulación de las franjas queda dada por

B =

2
N

p
C² + S². | (A15)

La función atan2 se utiliza porque permite conservar correctamente el cuadrante de la fase. Sin embargo, el resultado se encuentra restringido al intervalo (−π, π], por lo que la fase obtenida corresponde a una fase envuelta. Esta ambigüedad debe resolverse posteriormente mediante un proceso de desenvolvimiento de fase.

Apéndice B: Detalles computacionales del modelo 3D

### 1. Máscara por modulación

La máscara de píxeles válidos se definió a partir de la modulación B(x, y) mediante

M(x, y) = (
1, B(x, y) ≥ Bmin,
0, B(x, y) < Bmin.

(B1)

El umbral se tomó como una fracción del máximo de modulación:

Bmin = α m´ax
x,y
B(x, y), | 0 < α < 1. | (B2)

Para el caso del peluche, esta máscara conservó aproximadamente el 69,2 % de los píxeles del campo de visión.

### 2. Registro mediante ICP

El registro entre vistas se intentó mediante ICP (Iterative Closest Point). Este algoritmo busca una rotación R y una traslación t que permitan alinear una nube de puntos con otra. De forma general, esto puede escribirse como la minimización de la distancia entre puntos correspondientes:

(R

∗

, t∗
) = arg m´ın
R,t

X

i

∥Rpi + t − qi∥

2
. (B3)

En esta expresión, pi representa un punto de la vista que se desea alinear, mientras que qi corresponde al punto más cercano en la nube de referencia. En el proyecto, este procedimiento no logró una alineación estable debido a que las vistas no fueron tomadas con una base rotatoria calibrada.

### 3. Triangulación de la nube de puntos

Como la nube de puntos proviene de una imagen, la conectividad entre píxeles vecinos es conocida. Cada grupo de cuatro píxeles válidos se dividió en dos triángulos:

T1 = {Px,y, Px+1,y, Px,y+1}, | (B4)
T2 = {Px+1,y, Px+1,y+1, Px,y+1}. | (B5)

Con estos triángulos se construyó la superficie del objeto y posteriormente se exportó la malla en formato STL.

Apéndice C: Código en Python y carpeta del proyecto

https://drive.google.com/drive/folders/1ExhKkfreIYfPXyjCt76jSVYXKV3oAGX6?usp=sharing (https://drive.google.com/drive/folders/1ExhKkfreIYfPXyjCt76jSVYXKV3oAGX6?usp=sharing)

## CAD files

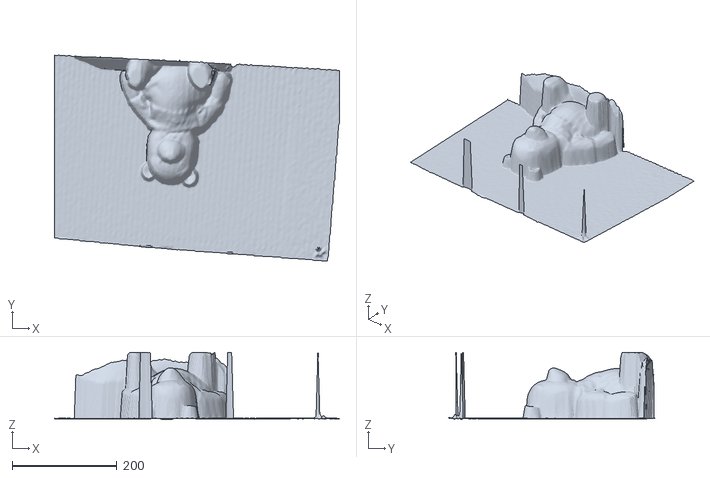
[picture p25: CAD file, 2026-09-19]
results/pooh/pooh.stl
544.2 x 394.1 x 128.2

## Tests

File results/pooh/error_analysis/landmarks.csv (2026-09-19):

name | real_cm | x | y | radius_px
Pie Derecho | 23.0 | 338.8 | 297.16 | 5
Pie Izquierdo | 23.5 | 240.96 | 299.27 | 5
Mano Derecha | 14.0 | 378.46 | 292.92 | 5
Mano Izquierda | 14.5 | 224.57 | 288.69 | 5
Oreja Derecha | 5.0 | 327.16 | 130.57 | 5
Oreja Izquierda | 4.8 | 255.24 | 139.56 | 5
Ojo Derecho | 13.3 | 310.24 | 160.18 | 5
Ojo Izquierdo | 13.3 | 274.81 | 162.83 | 5
Nariz | 17.8 | 292.79 | 171.82 | 5
Panza | 16.0 | 298.61 | 269.13 | 5
Camisa | 14.5 | 299.66 | 225.23 | 5
